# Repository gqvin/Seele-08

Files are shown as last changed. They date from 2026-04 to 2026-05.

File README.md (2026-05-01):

# Seele-08
Upgraded 2WD Gantry for the Sovol SV08 (AWD coming soon!)



Uses a modified [Monolith](https://github.com/Monolith3D/Monolith_Gantry/tree/main) belt path by CloakedWayne.

## Benefits:
* Shorter belt path compared to stock (Higher Accelerations!)
* Lighter Gantry Parts
* Entirely pinned
* Double Shear (With Long Shaft Motors)
* Better Tensioner Design
* Only 3mm X loss and 2mm Y loss with stock toolhead (Reaches stock nozzle brush!)
* No new rails, extrusions, or belts needed!
* Better compatability with toolheads that mount probe under the X extrusion
* No need for dehubbed pulleys

## BOM:
| **Part** | **Qty** | **Store/Notes** | 
| :--- | :--- | :--- |
| Pin M5x30mm | 10 | | 
| Pin M5x22mm | 2 | | 
| GT2 20T 6mm Idler | 6 | At least 2 have to be genuine gates (the two in AB mounts) | 
| F695 Bearing | 18 | Can also harvest 8 smooth idlers off of stock gantry and only buy 2 |
| 10x5x1mm Shim | 10 | | 
| 10x5x0.5mm Shim | 12 | | 
| GT2 20T 6mm Pulley | 2 | | 
| Long Shaft Motors | 2 | Recommended LDO 42STH48 - 2504 | 
| M3 Hardware | n/a | Heat Sets, SHCS | 
| M4 Hardware | n/a | BHCS/SHCS, Nuts | 

## Printing:
Standard Voron Settings (4 Walls, 5 Top/Bottom Layers, 40% Gyroid/TMPS-D) <br/>
Front Idlers need supports. <br/>
Reaming for the pins may be needed. <br/>
It is recommended to print [Z-Belt Helpers](https://www.printables.com/model/927729-sovol-sv08-z-belt-helper) by Nadir as you will be swapping out the Z joints. <br/>
If you are reusing the stock toolhead, print the belt clips from this repository. <br/>
You need to print some sort of Z-Chain Relocation mod. I recommend and used [these](https://www.printables.com/model/1320159-sv08-under-gantry-cable-chain-mount-for-sovol-cabl). <br/>

## Acknowledgement: 
**CloakedWayne** for designing the original belt path that this gantry uses.

## Future Goals:
* 9mm Belt Support
* AWD Support
* Support for 2wd with stock motors

## Changes:
* 2wd 6mm release
* Stronger 2WD Idlers
* Changed tolerances significantly and allowed for more standard screw lengths
* I have a [printables project](https://www.printables.com/model/1706696-seele-08-sovol-sv08-gantry) too if one prefers 
<br/><br/><br/><br/>
This work is licensed under a
[Creative Commons Attribution-NonCommercial-ShareAlike 4.0 International License][cc-by-nc-sa].

[][cc-by-nc-sa]

[cc-by-nc-sa]: http://creativecommons.org/licenses/by-nc-sa/4.0/
[cc-by-nc-sa-image]: https://licensebuttons.net/l/by-nc-sa/4.0/88x31.png
[cc-by-nc-sa-shield]: https://img.shields.io/badge/License-CC%20BY--NC--SA%204.0-lightgrey.svg

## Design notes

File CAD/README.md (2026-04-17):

build it from cad <br/>
some notes: <br/>
* don't overtighten z joint screws
* you need to replace z joints by sliding them all the way to the maximum z they can reach and reuse those screws
* the z belt clip things require you to snip off the locating tabs inside (you will understand once you get there)
* assembly of AB joints are convoluted, you need to put in the 2 m3x40 BEFORE attaching any motor screws
* Idlers are BFI (beefy front idlers) style so make sure when tensioning to not misalign them.
* XY joints require you to reuse the screws for mounting to carriage and also mounting the x beam
* any screw that looks like it threads into a 5mm dia hole needs a heat set (i was too lazy to add them to the cad)
* also future cad models for different versions (awd, 9mm etc) will NOT be including screws and nuts in the cad cus it took way too long
* contant domeeps on discord if questions

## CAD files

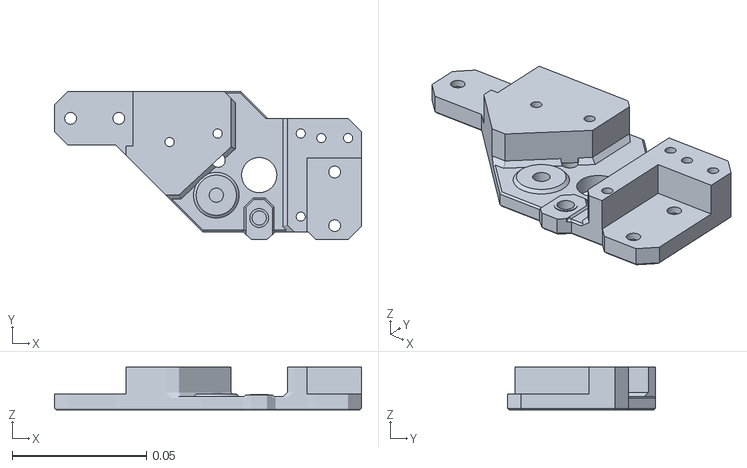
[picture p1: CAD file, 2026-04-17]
STLs/6mm/Gates Pulleys/Gates 6mm AB Mounts/AB Mount Assembly 6mm - Lower A.stl
0.114 x 0.0552 x 0.016

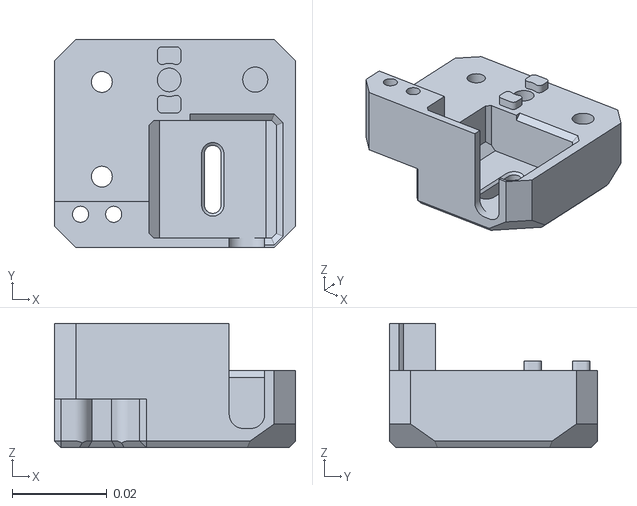
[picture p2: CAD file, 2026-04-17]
STLs/6mm/Gates Pulleys/Gates 6mm Idlers/Idler Assembly 6mm - Left Lower.stl
0.0509 x 0.044 x 0.0262

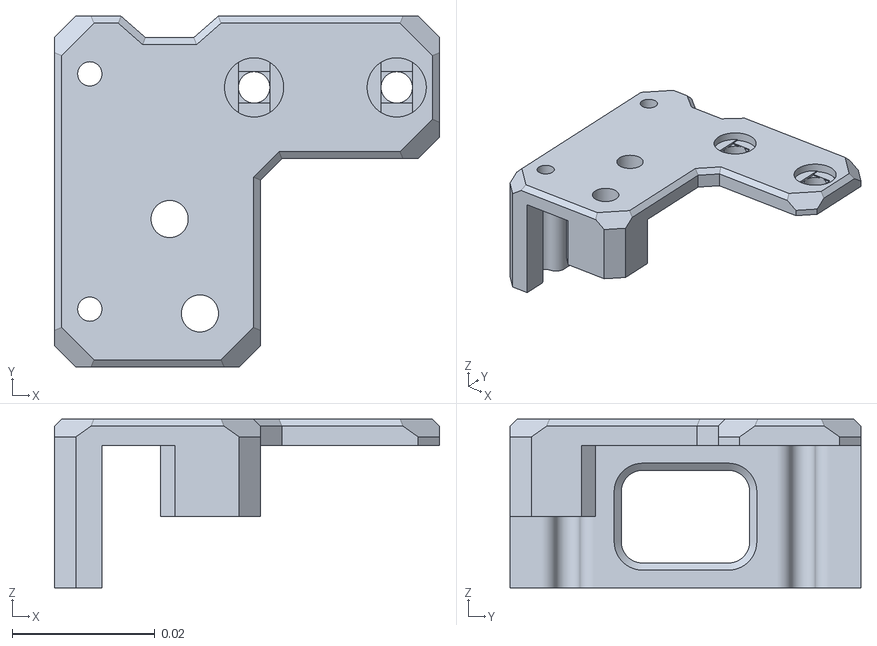
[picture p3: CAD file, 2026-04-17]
STLs/6mm/Gates Pulleys/Gates 6mm XY Joints/XY Joint Assembly 6mm - Left Upper.stl
0.054 x 0.0492 x 0.0237

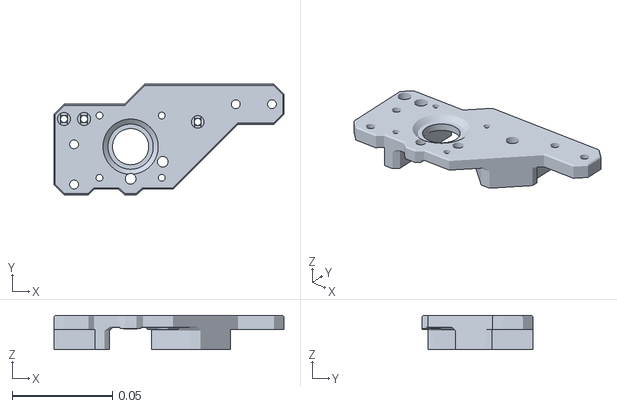
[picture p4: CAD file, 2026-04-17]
STLs/6mm/Gates Pulleys/Gates 6mm AB Mounts/AB Mount Assembly 6mm - Upper B.stl
0.115 x 0.0552 x 0.017

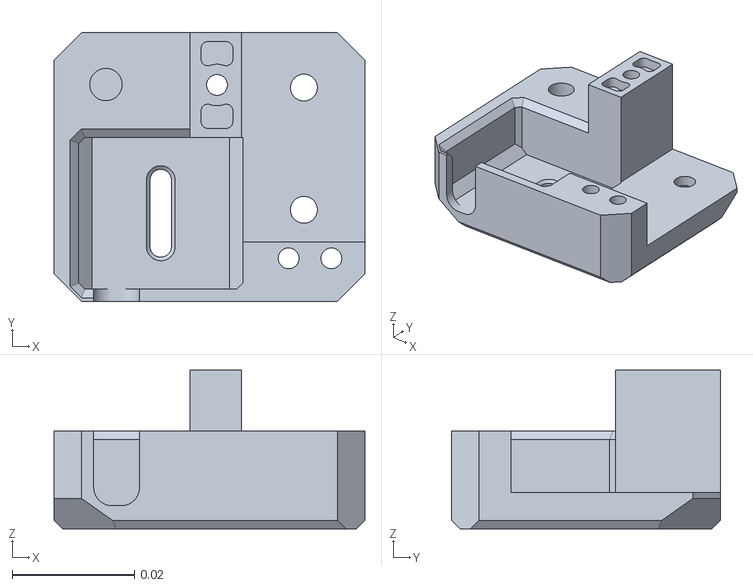
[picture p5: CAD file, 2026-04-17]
STLs/6mm/Gates Pulleys/Gates 6mm Idlers/Idler Assembly 6mm - Right Lower.stl
0.0509 x 0.044 x 0.026

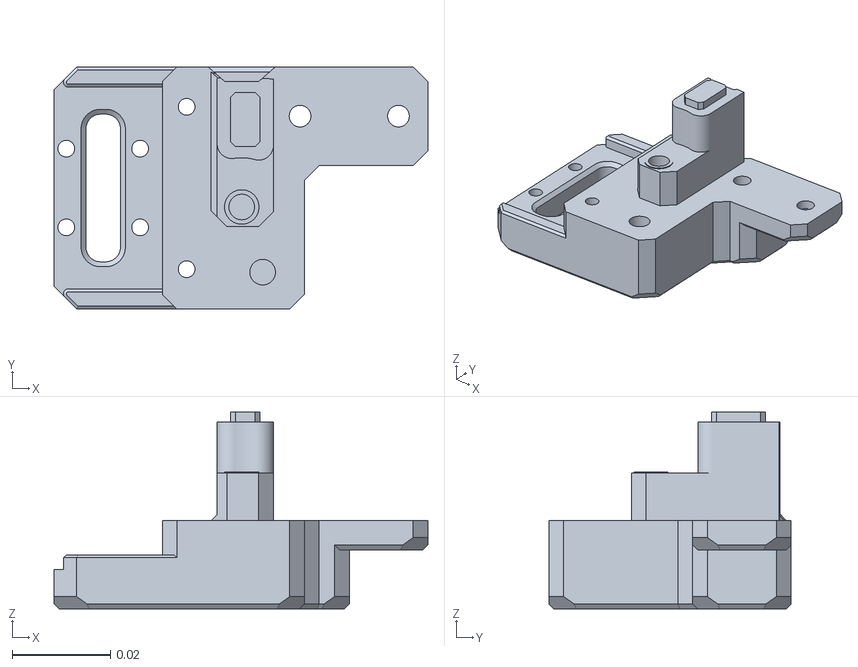
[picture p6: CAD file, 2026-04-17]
STLs/6mm/Gates Pulleys/Gates 6mm XY Joints/XY Joint Assembly 6mm - Left Lower.stl
0.076 x 0.0492 x 0.04

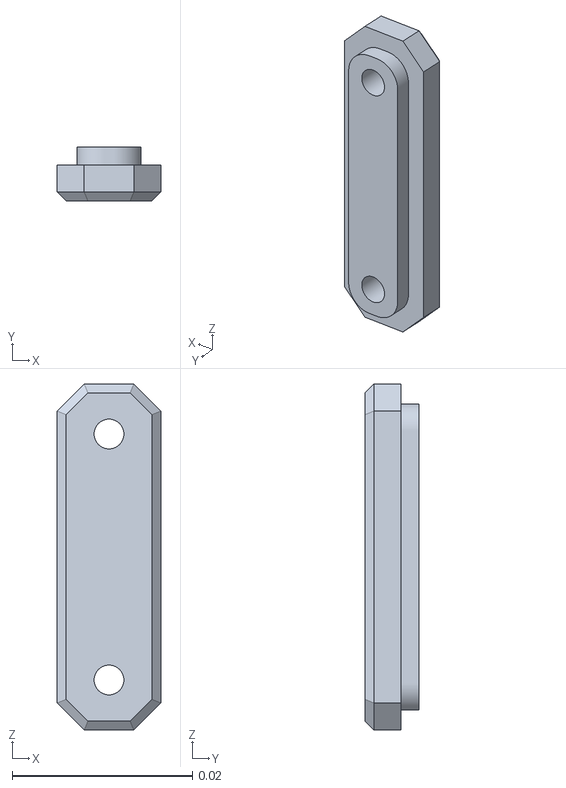
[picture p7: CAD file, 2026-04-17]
STLs/6mm/Gates Pulleys/Gates 6mm Idlers/2x Idler Assembly 6mm - Cover.stl
0.0115 x 0.006 x 0.0384

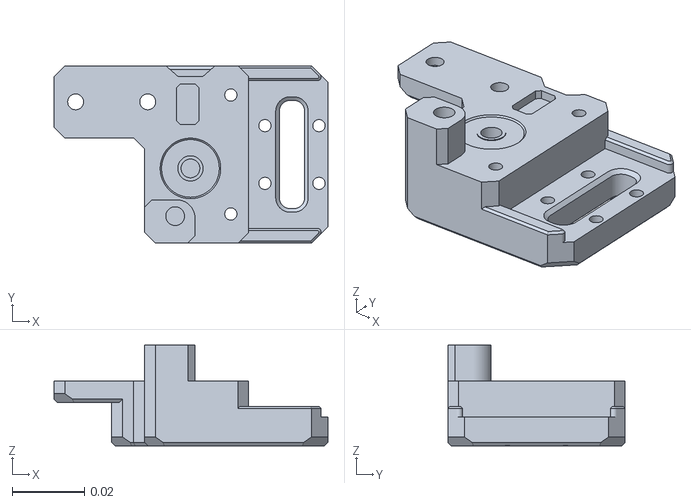
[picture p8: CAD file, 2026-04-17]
STLs/6mm/Gates Pulleys/Gates 6mm XY Joints/XY Joint Assembly 6mm - Right Lower.stl
0.076 x 0.0492 x 0.028

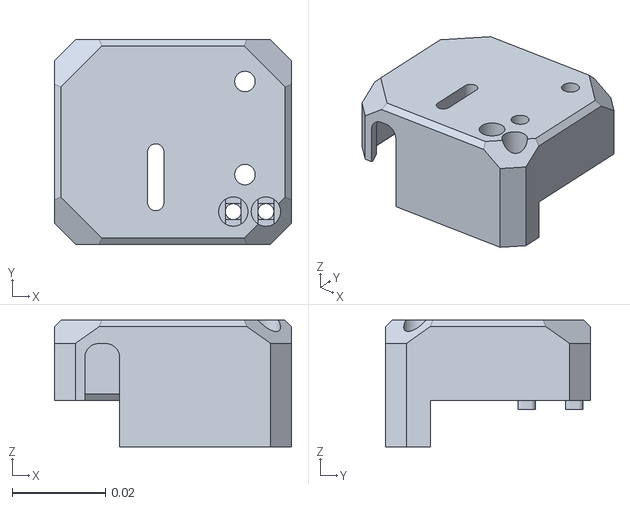
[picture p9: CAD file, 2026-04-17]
STLs/6mm/Gates Pulleys/Gates 6mm Idlers/Idler Assembly 6mm - RIght Upper.stl
0.0509 x 0.044 x 0.0272

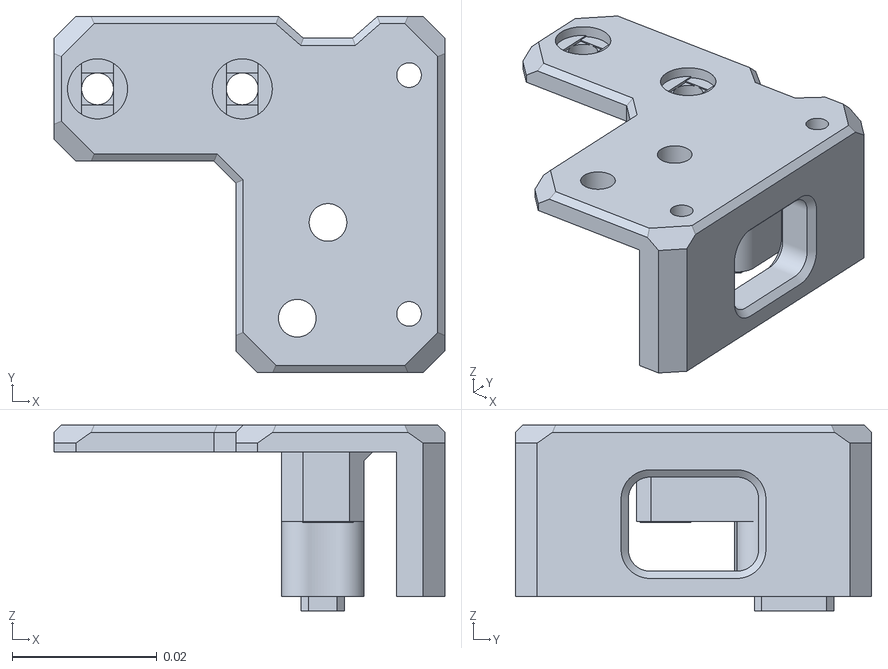
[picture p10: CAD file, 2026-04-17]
STLs/6mm/Gates Pulleys/Gates 6mm XY Joints/XY Joint Assembly 6mm - Right Upper.stl
0.054 x 0.0492 x 0.0257

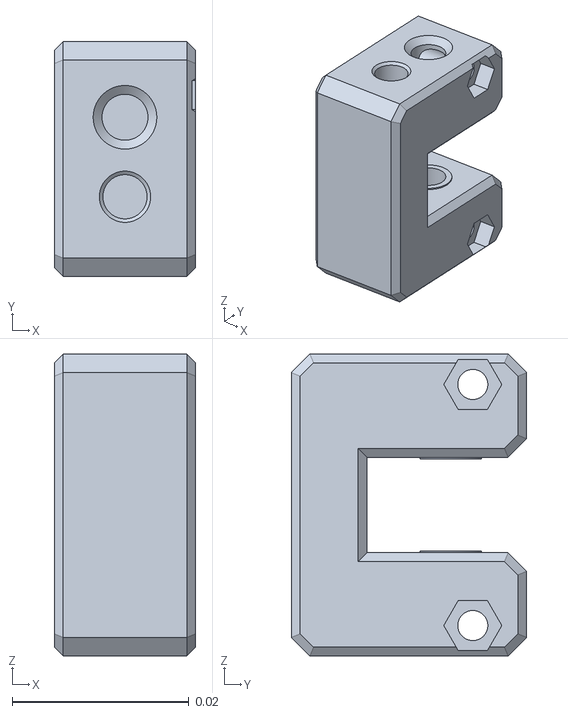
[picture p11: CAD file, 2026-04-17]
STLs/6mm/Gates Pulleys/Gates 6mm Idlers/Idler Assembly 6mm - Part 2.stl
0.016 x 0.0266 x 0.0342

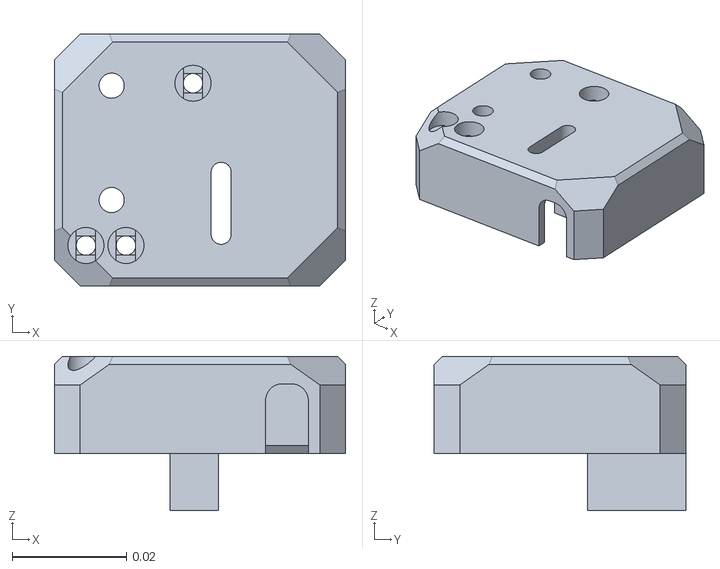
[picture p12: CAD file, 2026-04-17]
STLs/6mm/Gates Pulleys/Gates 6mm Idlers/Idler Assembly 6mm - Left Upper.stl
0.0509 x 0.044 x 0.027

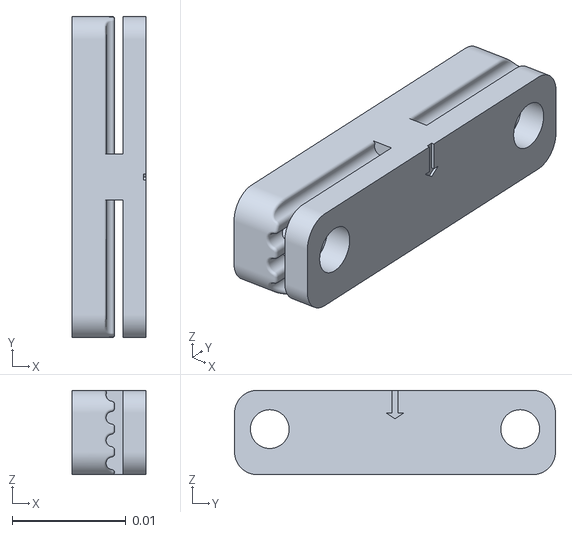
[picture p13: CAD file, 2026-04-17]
STLs/2x Belt Clip.stl
0.0065 x 0.0282 x 0.0074

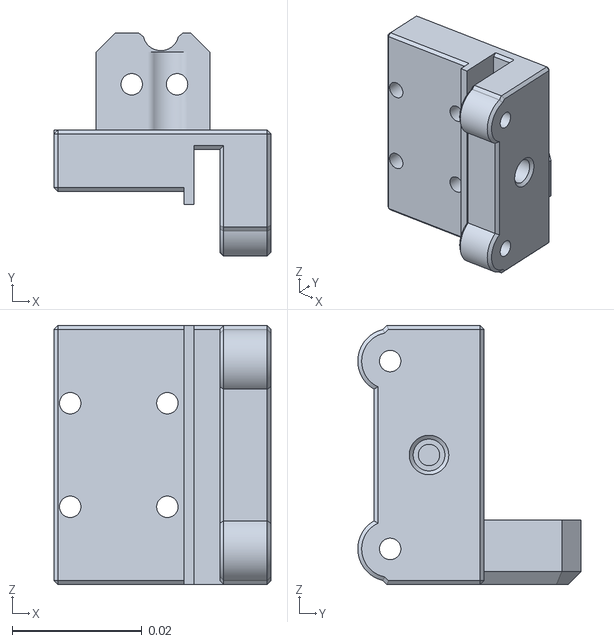
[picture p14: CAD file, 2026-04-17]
STLs/Slim Z Joints/Seele 08 - Front Left.stl
0.0335 x 0.0345 x 0.04

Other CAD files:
STLs/6mm/Gates Pulleys/Gates 6mm AB Mounts/AB Mount Assembly 6mm - Upper A.stl
STLs/6mm/Gates Pulleys/Gates 6mm AB Mounts/AB Mount Assembly 6mm - Lower B.stl
STLs/6mm/Gates Pulleys/Gates 6mm Idlers/Idler Assembly 6mm - Part 1.stl
STLs/Slim Z Joints/Seele 08 - Back Left.stl
STLs/6mm/Gates Pulleys/Gates 6mm AB Mounts/2x AB Mounts 6mm R2 - Double Shear Holder.stl
STLs/Slim Z Joints/Seele 08 - Back Right.stl
STLs/Slim Z Joints/Seele 08 - Front Right.stl

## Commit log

2026-04-02 Create XY Joints
2026-04-03 Added 6mm 2wd STLs
    [Back Left Z.stl, Back Right Z.stl, Double Shear Holder 2x.stl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]
2026-04-17 6mm Gates 2WD release ver.
    [2x AB Mounts 6mm R2 - Double Shear Holder.stl, 2x Idler Assembly 6mm - Cover.stl, AB Mount Assembly 6mm - Lower A.stl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]
2026-04-17 cad! release 1
    [2x Belt Clip.stl]
2026-05-01 Add link to printables project in README
2026-10-15 Added inverted motor mounts
2026-10-15 Add note about motor mounting options

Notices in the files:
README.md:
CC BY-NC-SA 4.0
